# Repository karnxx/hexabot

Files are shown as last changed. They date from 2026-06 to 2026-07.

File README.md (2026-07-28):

# HEXABOT
- a 6-legged robot with 3 segments.
- i want to make this robot, as i wanna get into robotics more, and its fun to make robots.
- this robot will first appear dead (no movements and all), then when somebody comes closer to it, will launch at them, something like a jumpscare from fnaf.








## [CAD](https://a360.co/4w0xuk9)
- cadded using autodesk fusion
- cadded electronic placements too

## [BOM](https://docs.google.com/spreadsheets/d/1mATnKwj9ZYp3htSjrHEwdiJQ4OFsj6mQfeVdPdykUfI/edit?usp=sharing)
- 1$ = 94₹


## ELECTRONICS
- make sure everything has common gnd.


## FIRMWARE
- made using [bottango](https://www.bottango.com/)
- ive made the joints and a basic walk animation, which u can download from bottango_model.btngo

# Parts List (INR ₹)

| Part | Description | Qty | Unit Price (₹) | Total (₹) | Link |
|---|---|-----:|---:|---:|---|
| DS3225 | For everything, 25kg·cm, 0.16s/60° | 22 | 314 | 6908 | https://robocraze.com/products/mg995-servo-motor |
| PCA9685 | Servo controller | 2 | 229 | 458 | https://robocraze.com/products/pca9685-16-channel-servo-motor-driversoldered |
| Pi Zero 2W | SBC | 1 | 1800 | 1800 | https://robu.in/product/raspberry-pi-zero-wireless-wh-pre-soldered-header |
| HC-SR04 | To detect person | 2 | 84 | 168 | https://robocraze.com/products/hc-sr-04-ultrasonic-sensor |
| Speaker Amp | To make speaker louder | 1 | 58 | 58 | https://robu.in/product/pam8403-mini-5v-digital-amplifier-board-switch-potentiometer |
| Speaker | Speaker | 1 | 224 | 224 | https://www.flyrobo.in/4r-3w-40mm-mini-power-amplifier-speaker |
| 2S LiPo 3000mAh 30C | Battery | 1 | 2105 | 2105 | https://robu.in/product/orange-3300mah-2s-25c-7-4v-lithium-polymer-battery-pack-lipo |
| 200W 20A Buck Converter | For servos | 1 | 339 | 339 | https://robu.in/product/200w-20a-dc-dc-buck-converter-step-down-module-constant-current-led-driver-module |
| Mini Buck Converter | For Raspberry Pi | 1 | 29 | 29 | https://robu.in/product/mini-360-step-down-buck-converter-power-module |
| LiPo Charger | To charge LiPo | 1 | 336 | 336 | https://robu.in/product/b3ac-compact-balance-charger-2s-3s-lipo |
| M2 Bolts | For servo horns and mounting electronics | 30 | 3 | 90 | https://onlyscrews.in/products/m2-x-25mm-phillips-csk-ss-304-screw-dia-2mm-length-25mm |
| M2 Nuts | Same as above | 30 | 1 | 30 | https://onlyscrews.in/products/m2-hex-nut-mild-steel-dia-2mm |
| M2 Nyloc Nuts | Same as above | 15 | 6 | 90 | https://onlyscrews.in/products/m2-nyloc-nuts-ss304-dia-2mm |
| Servo Extension Wire | Extend servo cable length | 5 | 54 | 270 | https://robocraze.com/products/robocraze-servo-extension-cable-60cm-female-to-female |
| Header Pins | For soldering onto Pi Zero and amp | 1 | 100 | 100 | https://www.amazon.in/dp/B0DNMD4THF |
| Zip Ties | For securing battery | 5 | 0.8 | 4 | https://onlyscrews.in/products/3-6mm-x-150mm-white-color-multi-purpose-self-locking-nylon-industrial-grade-cable-zip-tie |

## Cost Summary

| Item | Amount (₹) |
|---|---:|
| Total Project Cost | **13,009** |

> Note: The provided CSV states a final total of **₹13,005**, but summing the listed line items results in **₹13,009**. The discrepancy is **₹4**.

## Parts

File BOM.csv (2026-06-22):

part | desc | qty | price | ttl | link
DS3225 | for everything, 25kgcm, 0.16/60deg | 22 | 314 | 6908 | https://robocraze.com/products/mg995-servo-motor?variant=40193009844377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
PCA9685 | servo controller | 2 | 229 | 458 | https://robocraze.com/products/pca9685-16-channel-servo-motor-driversoldered?variant=40193677721753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
Pi Zero 2W | sbc | 1 | 1800 | 1800 | https://robu.in/product/raspberry-pi-zero-wireless-wh-pre-soldered-header/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
HC-SR04 | to detect person | 2 | 84 | 168 | https://robocraze.com/products/hc-sr-04-ultrasonic-sensor?variant=40192340983961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
speaker amp | to make speaker louder | 1 | 58 | 58 | https://robu.in/product/pam8403-mini-5v-digital-amplifier-board-switch-potentiometer/?gad_source=1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
speaker | speaker yk | 1 | 224 | 224 | https://www.flyrobo.in/4r-3w-40mm-mini-power-amplifier-speaker?tracking=ads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
2S LiPo 3000mAh 30C | battery | 1 | 2105 | 2105 | https://robu.in/product/orange-3300mah-2s-25c-7-4v-lithium-polymer-battery-pack-lipo/?gad_source=1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
200W 20A buck converter | for servos | 1 | 339 | 339 | https://robu.in/product/200w-20a-dc-dc-buck-converter-step-down-module-constant-current-led-driver-module/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
mini buck converter | for rpi | 1 | 29 | 29 | https://robu.in/product/mini-360-step-down-buck-converter-power-module/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
lipo charger | to charge lipo | 1 | 336 | 336 | https://robu.in/product/b3ac-compact-balance-charger-2s-3s-lipo/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
m2 bolts | for servo horns, and screwing in the electronics | 30 | 3 | 90 | https://onlyscrews.in/products/m2-x-25mm-phillips-csk-ss-304-screw-dia-2mm-length-25mm
m2 nuts | same as above | 30 | 1 | 30 | https://onlyscrews.in/products/m2-hex-nut-mild-steel-dia-2mm
m2 nyloc nuts | same as above | 15 | 6 | 90 | https://onlyscrews.in/products/m2-nyloc-nuts-ss304-dia-2mm
servo extension wire | to extend the length of wire of servo | 5 | 54 | 270 | https://robocraze.com/products/robocraze-servo-extension-cable-60cm-female-to-female?variant=52665661948128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
header pins | for soldering onto pi zero and amp | 1 | 100 | 100 | https://www.amazon.in/UNIVERSAL-HUB-2-54mm-Female-Connector/dp/B0DNMD4THF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
zipties | for securing battery | 5 | 0.8 | 4 | https://onlyscrews.in/products/3-6mm-x-150mm-white-color-multi-purpose-self-locking-nylon-industrial-grade-cable-zip-tie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
(in inr₹) |  |  |  | 13005

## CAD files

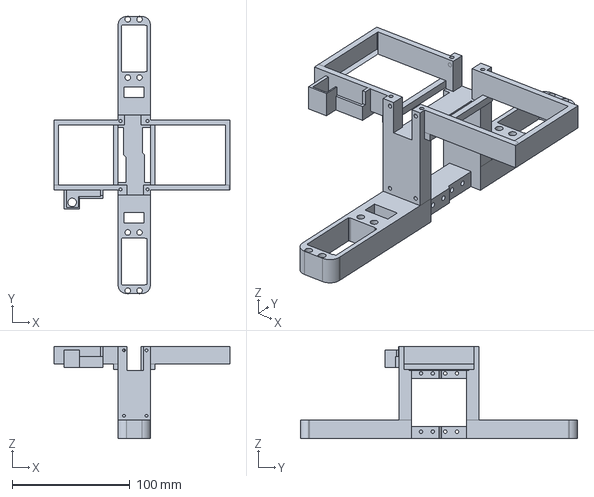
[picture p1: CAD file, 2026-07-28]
CAD/3dp/stp/1xmidseg.step
149.6 x 235.5 x 78.6 mm

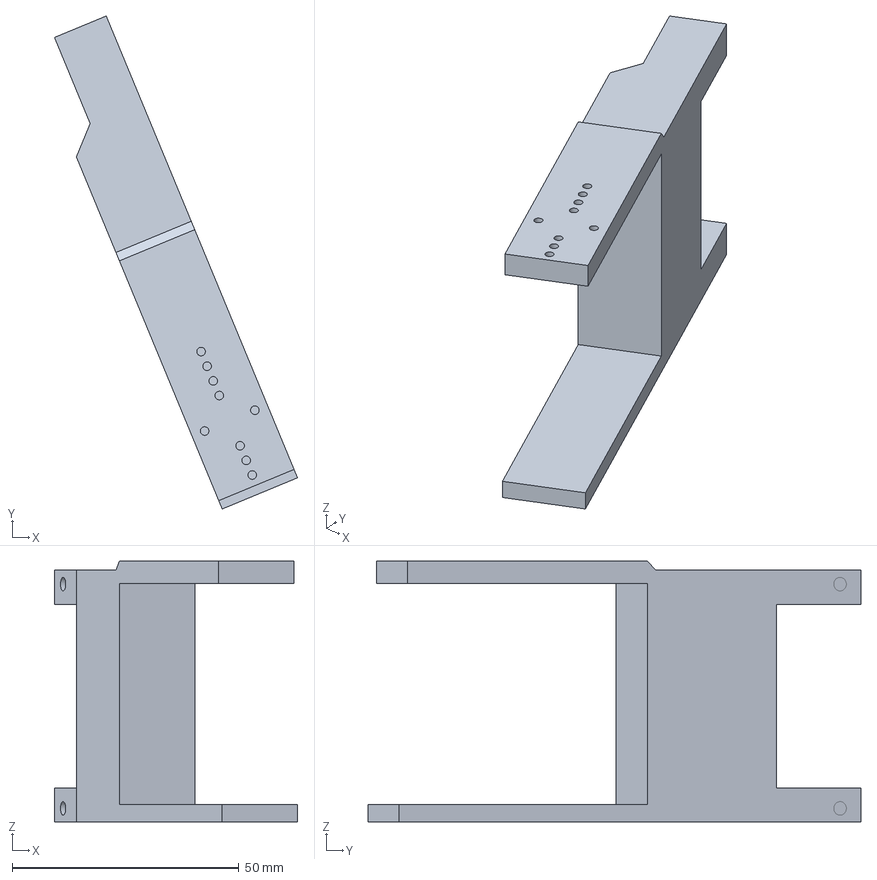
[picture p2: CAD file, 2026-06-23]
CAD/3dp/stp/3xleftsiderot.step
53.7 x 108.8 x 57.6 mm

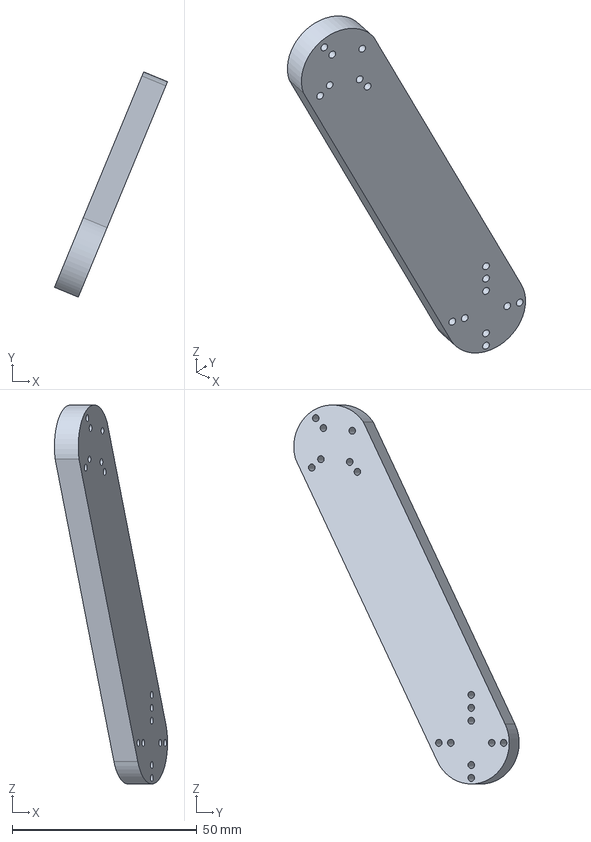
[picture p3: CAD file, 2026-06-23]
CAD/3dp/stp/6xbetweenclawandrot.step
30.6 x 61.0 x 102.7 mm

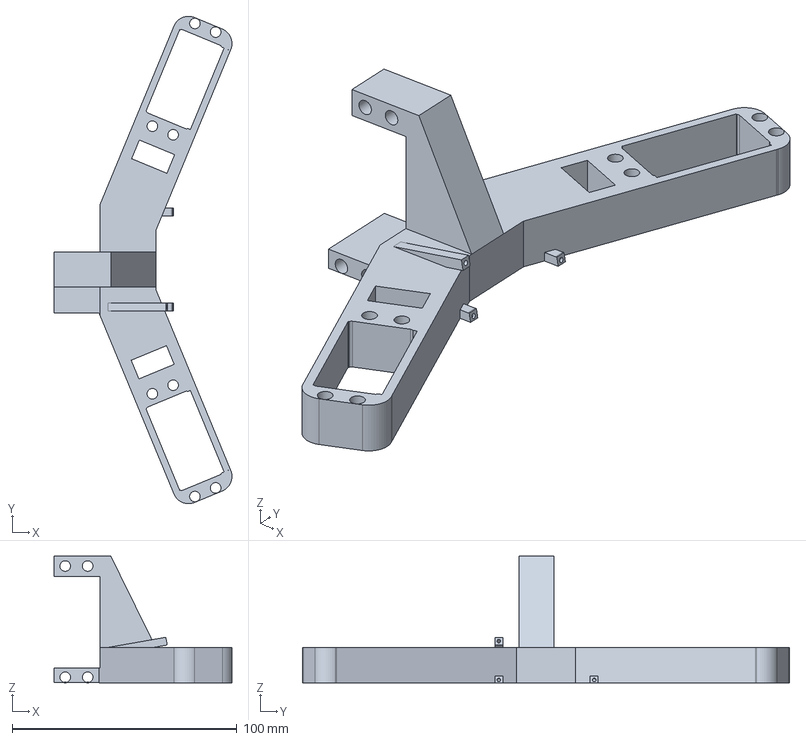
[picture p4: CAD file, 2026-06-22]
CAD/3dp/stp/1xsegment2.step
79.3 x 217.0 x 56.4 mm

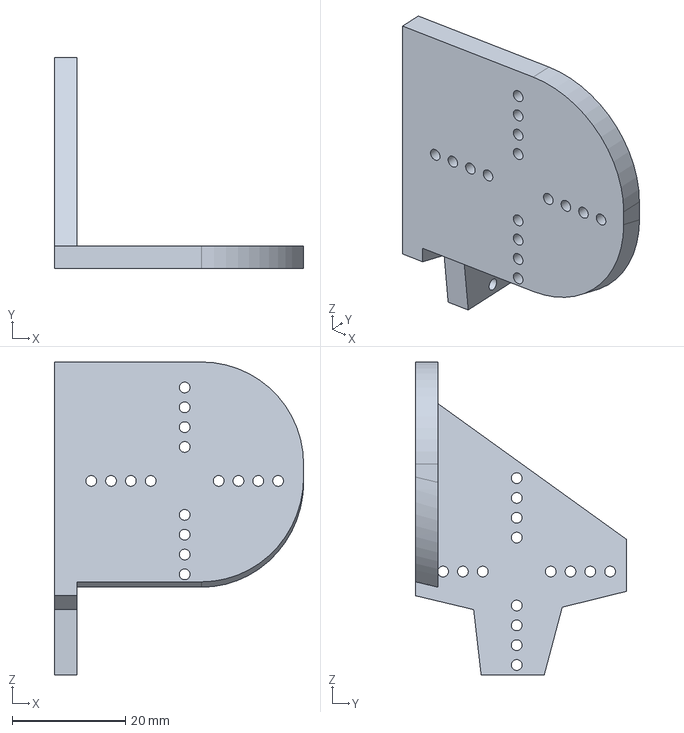
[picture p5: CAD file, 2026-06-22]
CAD/3dp/stp/1xmidrot.step
44.0 x 37.3 x 55.3 mm

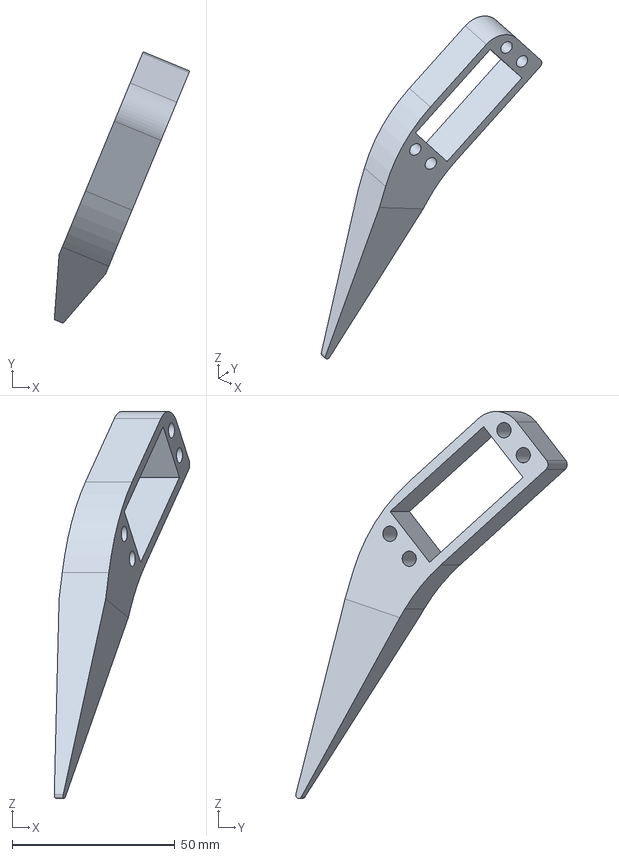
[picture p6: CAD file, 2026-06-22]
CAD/3dp/stp/6xclaw.step
41.6 x 83.4 x 118.9 mm

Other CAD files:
CAD/3dp/stp/thing.obj
CAD/3dp/stp/3xrightsiderot.step
CAD/3dp/stp/1xsegment.step
CAD/3dp/stp/1xmidrot (1).step
CAD/3dp/stl/1xmidrot (1).stl
CAD/3dp/stl/1xmidrot.stl
CAD/3dp/stl/1xmidseg.stl
CAD/3dp/stl/1xsegment.stl
CAD/3dp/stl/1xsegment2.stl
CAD/3dp/stl/3xleftsiderot.stl
CAD/3dp/stl/3xrightsiderot.stl
CAD/3dp/stl/6xbetweenclawandrot.stl
CAD/3dp/stl/6xclaw.stl

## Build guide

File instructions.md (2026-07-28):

# INSTRUCTIONS
### (make sure u 3dp everything before this)

- 1. add the servoes without horn to the mounting areas:

- (6 of these, 3 on either side)


- (total 4)


- (2 total)


- (2, either sides, on joining segments)


- (2 in the middle)


- (6 servos total for elbow)


totally, 22 servos, check the 3d model for more help (green things servos):


- 2. servo horn mounts
- first screw in all the horns to the servos
- mount all the servo horns here:

- 2-4 screws are optimal.
- after that, follow the 3d model and assemble accordingly.

- 3. electronic mounting
- make sure all wires are not being obstructed.
- mount the pca on both side of the mid seg, use bolts with force thread/heat insert or use self tapping screws. i reccomend screws.


- make sure all servos wires reach the pca.
- mount the battery in the middle area (Representated by the blue cuboid), and use zip ties as support (get the long ones).



- mount the speaker and the amplifier. the amp has a slide in area, where u just have to put it there and maybe add zip ties to secure it. and for the speakers, u can mount them anywhere, its your wish.



- after that mount the raspberry pi zero2 w here:



- 3. wiring
- 11 servos to one pca, 11 to the other, follow this wiring diagram:


- 4. firmware
- for firmware an easy method is to use bottango. ive made a btngo file, with all the joints modeled, so you can use that to create you own animations and stuff. 


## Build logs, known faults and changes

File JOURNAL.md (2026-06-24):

# hexabot 

a hexapod robot split into 3 segments.

# 2026-06-21: battery mounted and stuff.

**Total time spent: 0.1666666666666666666666666666666666666666666666666666666666666666666666666 hours**

so i mounted the battery, not rlly but lke i made where u can slide the battery and zip tie it. basically a stand type thing. here i will be able to yk mount the step downs. im kinda worried that it wud hit the other segments.  also made the bom, which is around 140 dollars. i just have to arrange the files and then i can submittt.
i didnt use lapse as this only took me liek 10 mins 



# 2026-06-20: spider body done

**Total time spent: 1 hour**

so i finished the body. it looks great rn. instead of using cv for human detection, im gnna use ultrasonic sensors, one in the front, other in back. then the pcas have 11 servos each. so 22 in total. using rpi zero 2 w for this. so i have to use 2 buck convertors, one for the pcas and one for the rpi zero 2 w. 


https://lapse.hackclub.com/timelapse/gv8gQ57M9d9G

# 2026-06-19: startedd making the body

**Total time spent: 0.41666 hours**

so i started making the body. joints between segemtns have 2 dofs. if it wud be possible i could swap the ends for like vacuum or som so that it could climb walls, yeah tht wud be cool, but not rn. anyways, yeah so i added 2 servos and got done with one segment to the mid. but the servo horn connectors thingeys look ugly. so i wud need some inspo for that.




# 2026-06-18: started with cad

**Total time spent: 1 hour**

so this hexapod robot, has 3 segments with 2 legs on each. the segments can twist and all too. then when it senses someone, it acts like its dead, then when they get close, it launches at them. so tday i started with cad, im replicating smtn like [this](https://www.youtube.com/watch?v=VC1T4whJ0OY). i cadded out 1 leg, and then mirrored that and another leg. i have to join them to make 1 segment now. then i have to mirror for all the segments and legs, after that i have to find a way to join the segments with their individual movements. 




https://lapse.hackclub.com/timelapse/2y0vX2pnm9Ri

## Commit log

2026-06-22 Rename hexabot bom - Sheet1.csv to BOM.csv
    [BOM.csv]
2026-06-22 added cad files
    [1xmidrot (1).step, 1xmidrot (1).stl, 1xmidrot.step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]
2026-06-23 added more cad files
    [3xleftsiderot.step, 3xrightsiderot.step, 6xbetweenclawandrot.step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]
2026-07-09 Create instructions for servo mounting
    Add initial instructions for servo installation.
2026-07-28 cad stuff added
    [1xmidseg.step, 1xmidseg.stl]
